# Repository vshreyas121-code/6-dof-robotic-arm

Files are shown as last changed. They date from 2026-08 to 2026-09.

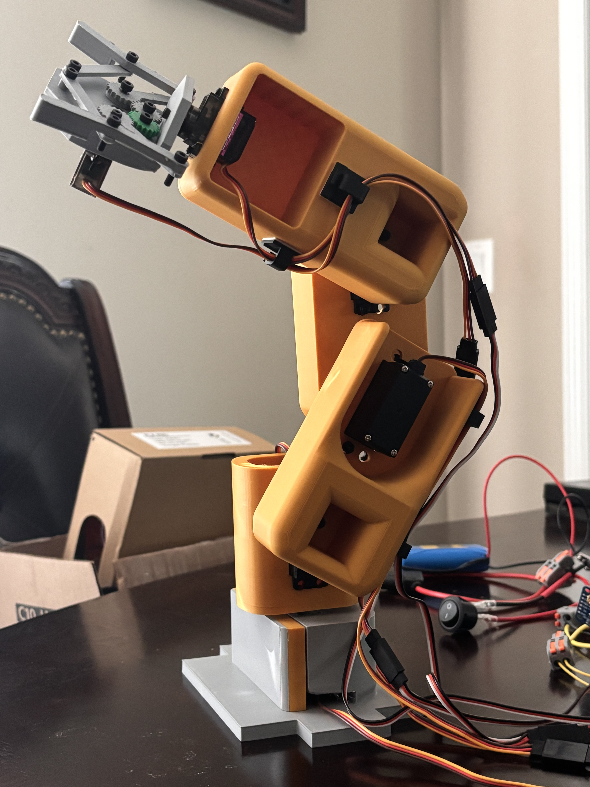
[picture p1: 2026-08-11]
images/finished-arm.jpeg

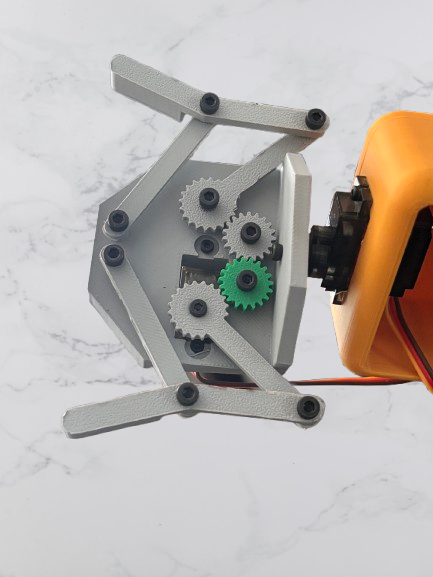
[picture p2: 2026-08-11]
images/gripper.png

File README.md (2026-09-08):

# DIY 6-DOF Robotic Arm

## 📌 Project Overview

This project documents the design, CAD modeling, assembly, wiring, and programming of a custom 6-DOF robotic arm. The robotic arm is controlled using an Arduino Mega 2560, a PCA9685 16-channel servo driver, and six positional servo motors. The mechanical components were designed in Onshape and assembled using 3D-printed parts, servo horns, screws, and hardware.

The arm is powered by a LiPo battery, fuse, switch, and 5V buck converter system. Servo angles are controlled through serial commands sent from a computer through the Arduino Serial Monitor.

The project provided practical experience in robotics, CAD design, embedded systems, servo control, electrical wiring, hardware-software integration, and mechanical troubleshooting.

---

## 🚀 Features

 -  6-DOF robotic arm movement
 - Individual servo motor control
 - Serial angle control through a computer
 - Arduino Mega 2560 control system
 - PCA9685 16-channel PWM servo driver
 - Custom robotic arm components designed in Onshape
 - 3D-printed mechanical assembly
 - External LiPo battery and 5V buck-converter power system
 - Servo angle constraints for safe operation
 - Modular and easy-to-understand Arduino code
 - Planned future autonomous pick-and-place and leader-follower control features

---

## 🛠 Hardware Components

 - Arduino Mega 2560
 - PCA9685 16-Channel Servo Driver
 - 4 MG995 Positional Servo Motors
 - 2 MG90S Positional Servo Motors
 - Custom 3D-Printed Robotic Arm Mechanical Assembly
 - LiPo Battery
 - Fuse and Fuse Holder
 - Power Switch
 - 5V Buck Converter
 - Jumper Wires
 - Servo Extension Wires
 - Screws, Nuts, and Servo Horns

---

## 💻 Software & Tools

 - Onshape
 - VS Code
 - Arduino Framework / Arduino Libraries
 - GitHub

---

## ⚙️ Technologies Used

 - Arduino Mega 2560
 - PCA9685 I2C PWM Servo Control
 - Onshape CAD Design
 - 3D Printing
 - Robotics & Automation
 - Hardware-Software Integration

---

## 📂 Project Structure

```
├── 📁cad/
│   ├── 📁step/
│   │   ├── 6-dof-robotic-arm.step
│   │   └── assembled-gripper.step
│   ├── 📁STL/
│   │   ├── 📁base/
│   │   │   ├── base-wall.stl
│   │   │   └── base.stl
│   │   ├── 📁elbow/
│   │   │   └── elbow.stl
│   │   ├── 📁gripper/
│   │   │   ├── 📁claw/
│   │   │   │   ├── left-claw.stl
│   │   │   │   └── right-claw.stl
│   │   │   ├── 📁gears/
│   │   │   │   ├── 2x-small-gear.stl
│   │   │   │   ├── big-gear-left.stl
│   │   │   │   └── big-gear-right.stl
│   │   │   ├── 2x-linkage.stl
│   │   │   └── palm.stl
│   │   ├── 📁shoulder/
│   │   │   └── shoulder.stl
│   │   ├── 📁waist/
│   │   │   └── waist.stl
│   │   └── 📁wrist/
│   │       └── wrist.stl
│   └── Onshape-Link.md
├── 📁code/
│   ├── 6 DOF Robotic Arm.ino
├── 📁docs/
│   ├── assembly-guide.pdf
│   └── wiring-diagram.png
├── 📁electronics/
│   ├── parts-list.pdf
│   └── wiring-diagram.png
├── 📁images/
│   ├── Robotic_Arm.mov
│   ├── finished-arm-cad.png
│   ├── finished-arm.jpeg
│   └── gripper.png
├── LICENSE
└── README.md

```

---

## 🔄 Working Principle

1. The LiPo battery provides power to the system through a fuse and power switch.
2. The battery voltage is sent to a buck converter, which supplies regulated 5V power to the Arduino Mega 2560, PCA9685 servo driver logic, and PCA9685 servo power rail.
3. The Arduino Mega communicates with the PCA9685 using I2C communication through the SDA and SCL pins.
4. The PCA9685 generates PWM signals for each servo motor.
5. Six positional servos are connected to PCA9685 channels 0 through 5.
6. The user enters six requested servo angles through the computer Serial Monitor.
7. The Arduino reads the serial command, applies safe angle limits, and commands each servo to move to its requested position.
8. The robotic arm performs the requested movement in real time.

---

## 🎯 Skills Demonstrated

 - Robotics
 - Arduino Development
 - Servo Motor Control
 - Serial Communication
 - CAD Design
 - 3D Printing
 - Electrical Wiring and Power Distribution
 - Hardware Integration
---

## 👨‍💻 My Contribution

 - Designed the complete robotic arm in Onshape.

 - Created CAD models for the mechanical arm components and exported files for fabrication.

 - Assembled the robotic arm using custom 3D-printed components, positional servos, servo horns, screws, nuts, and washers.

 - Designed and documented the power-distribution system using a LiPo battery, fuse, switch, and 5V buck converter.

 - Wired the Arduino Mega 2560, PCA9685 servo driver, and six servo motors.

 - Programmed the Arduino using VS Code.

 - Created serial-based servo-angle control for all six arm joints.

 - Tested, calibrated, and optimized servo motor movement and mechanical alignment.

 - Performed complete hardware-software integration and system testing.

---
## 🎥 Video

https://github.com/user-attachments/assets/5076b947-41e4-44dd-bf85-272afc0f2e92

---
## 📚 Author

**Shreyas Venkatachalam**

High School student interested in robotics, mechanical design, and embedded systems.

I designed, modeled, assembled, and programmed this 6-DOF robotic arm using Onshape, 3D-printed components, an Arduino Mega 2560, a PCA9685 servo driver, and six servo motors. This project allowed me to explore robotic motion, CAD design, 3D printing, electrical wiring, serial communication, and iterative troubleshooting.

 - Email: [VShreyas121@gmail.com](mailto:VShreyas121@gmail.com)

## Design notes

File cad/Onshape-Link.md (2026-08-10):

https://cad.onshape.com/documents/33eb4faf4d72cb4e8d812189/w/d14da05585980880eb853401/e/e9817a7469a7e6512d3307ce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

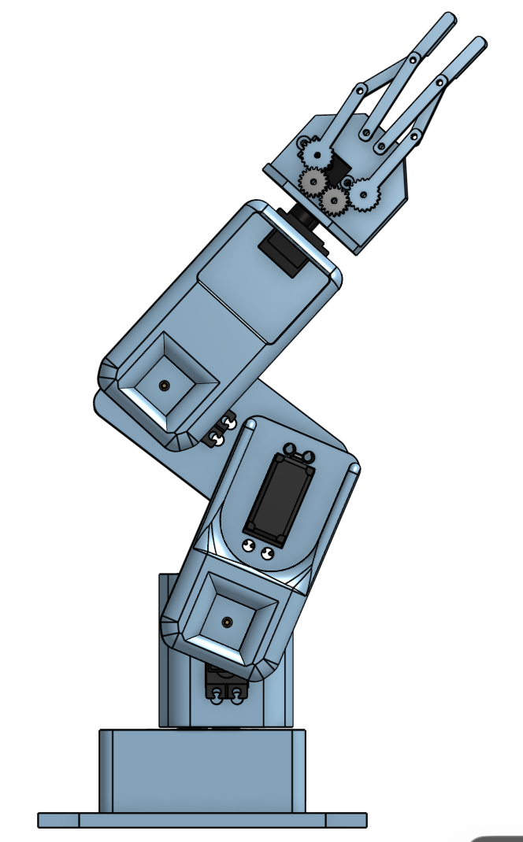
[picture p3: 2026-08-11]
images/finished-arm-cad.png

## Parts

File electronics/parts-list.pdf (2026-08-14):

Parts List

1. 12.6 V LiPo Battery 3000 mAh
2. Fuse (optional)
3. Switch
4. 12.6 V to 5 V DC Buck Converter
5. Arduino Mega 2560
6. PCA9685 Servo Controller
7. 1 to 2 Lever Wire Connecters (optional)
8. M2, M2.5, M3 screws
9. Jumper Wires

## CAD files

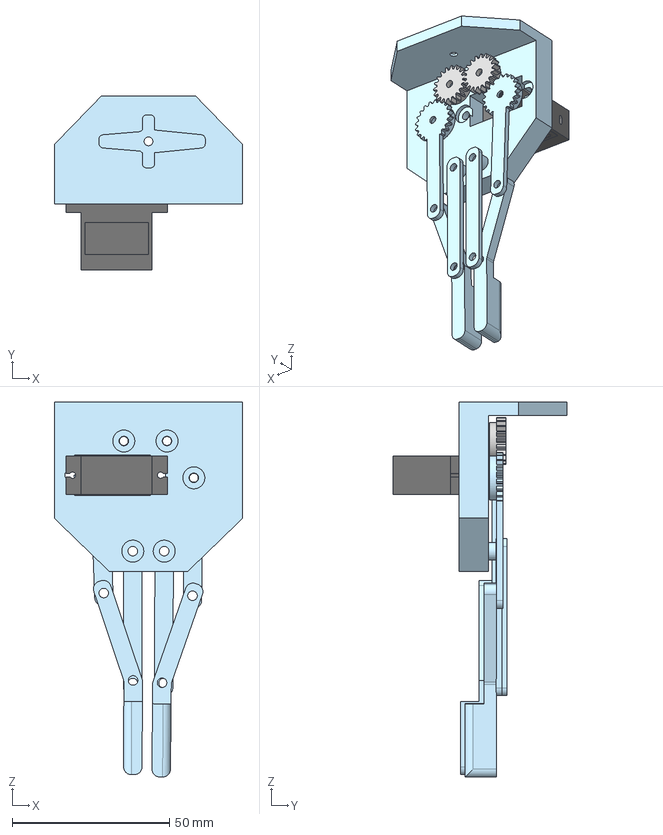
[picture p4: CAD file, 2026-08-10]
cad/step/assembled-gripper.step
60.0 x 55.5 x 119.4 mm
Cylindre001
axe
Tube002
Cylindre
Small gear x 2
Cylindre002
Tube001
base001
Tube
etiquette001
Big gear Right
Big gear Left
etiquette

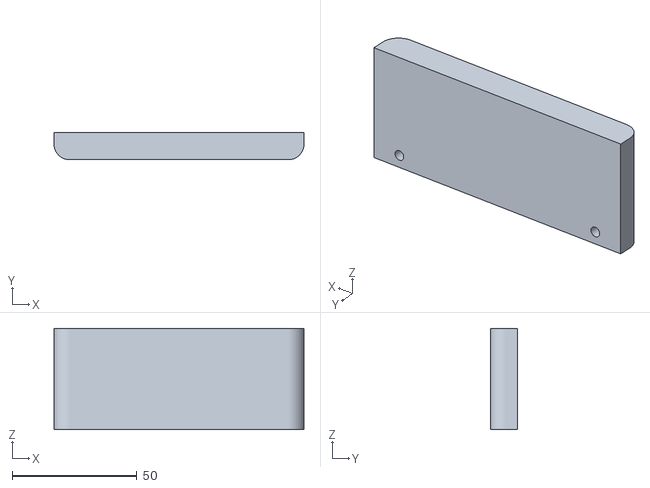
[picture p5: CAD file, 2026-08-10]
cad/STL/base/base-wall.stl
100.0 x 11.0 x 40.5

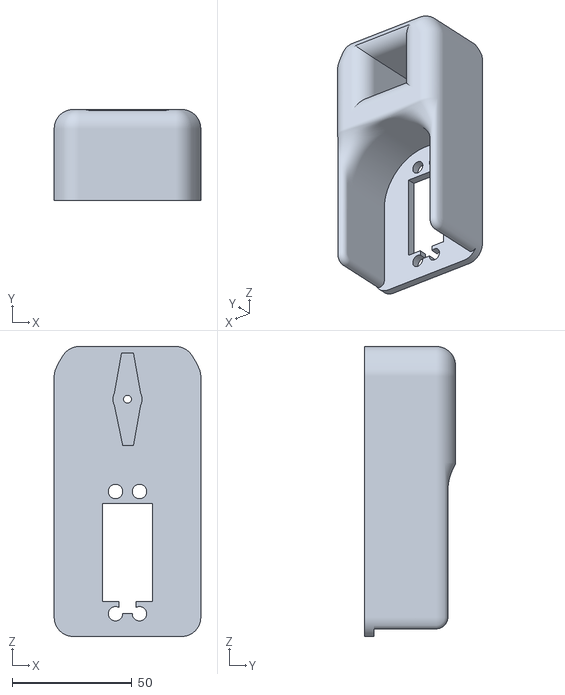
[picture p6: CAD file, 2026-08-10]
cad/STL/elbow/elbow.stl
61.2 x 38.0 x 121.0

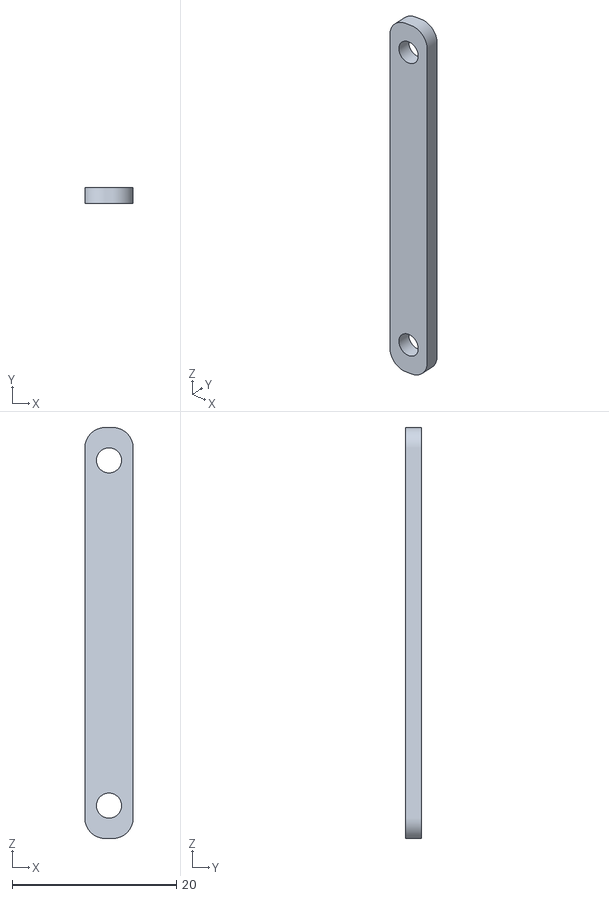
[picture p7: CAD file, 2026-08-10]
cad/STL/gripper/2x-linkage.stl
5.89 x 2.00 x 50.0

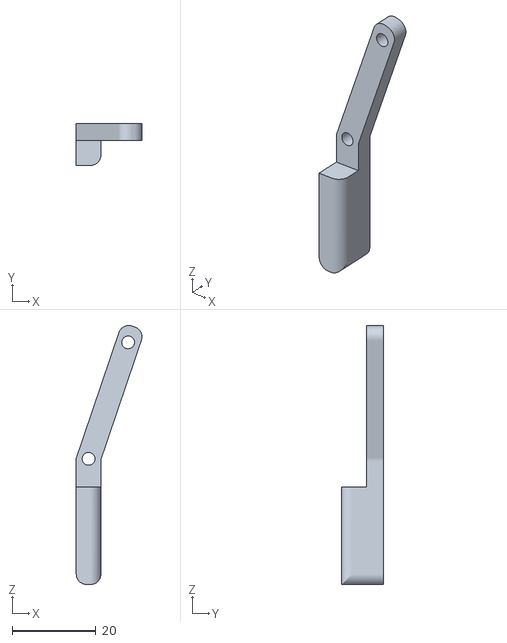
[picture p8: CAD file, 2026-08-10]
cad/STL/gripper/claw/right-claw.stl
15.7 x 10.0 x 61.8

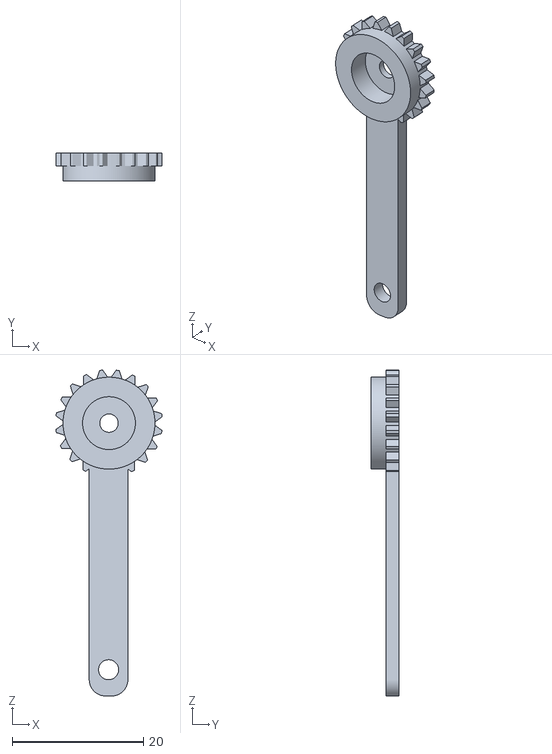
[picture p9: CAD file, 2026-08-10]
cad/STL/gripper/gears/big-gear-right.stl
16.2 x 4.30 x 49.6

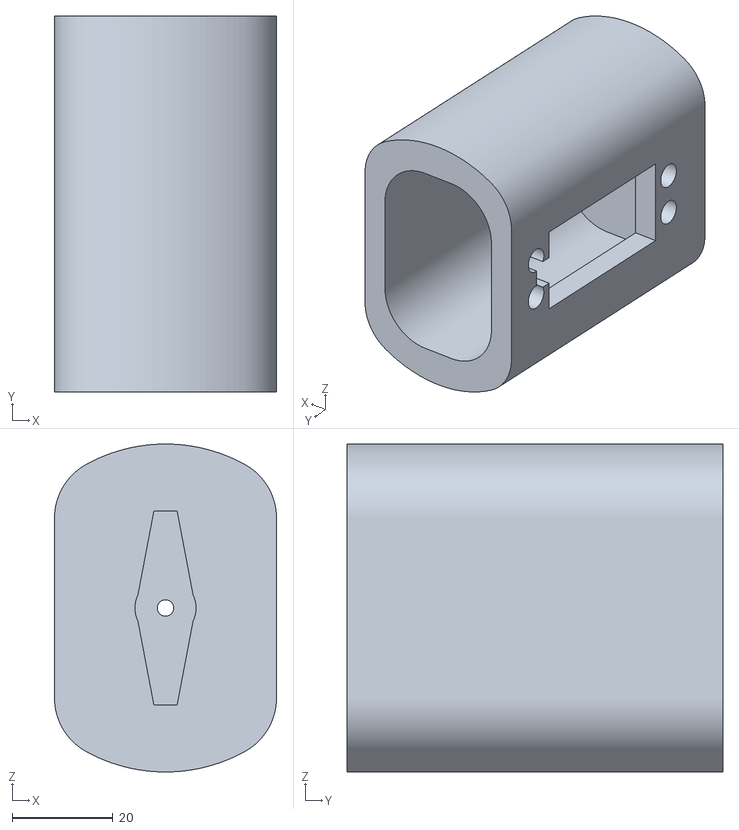
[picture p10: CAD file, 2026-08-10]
cad/STL/waist/waist.stl
44.0 x 74.5 x 65.0

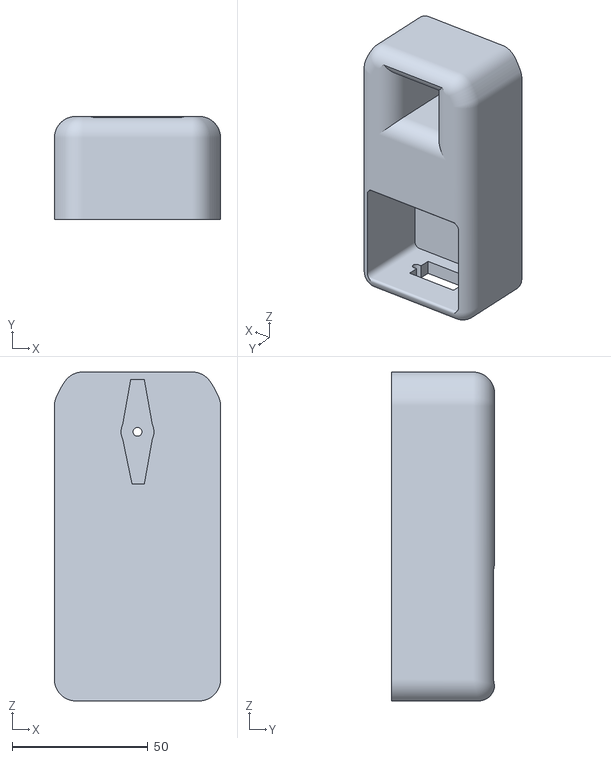
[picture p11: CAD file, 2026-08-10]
cad/STL/wrist/wrist.stl
61.2 x 38.0 x 121.0

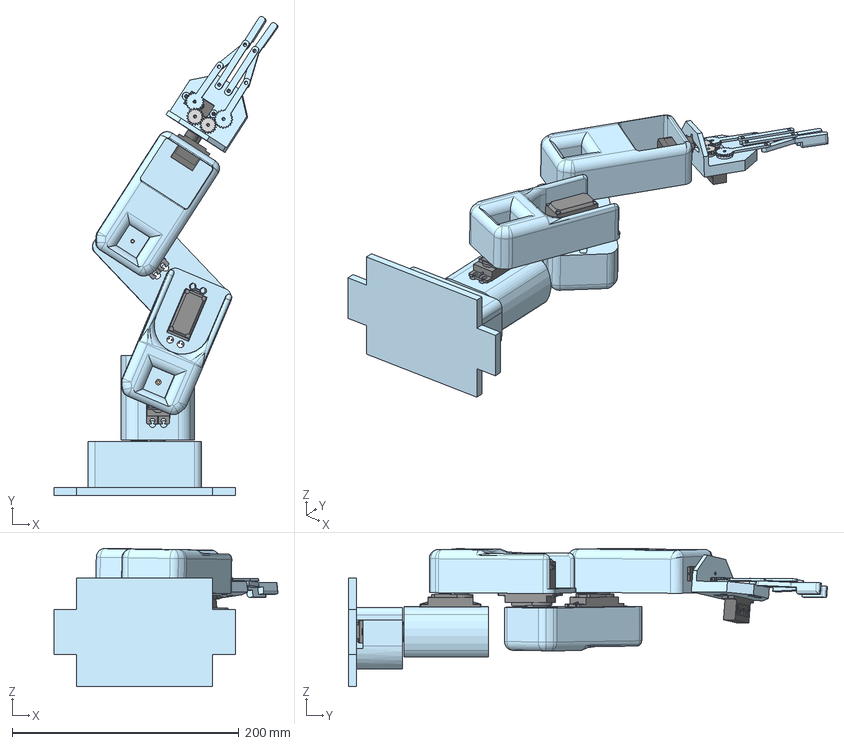
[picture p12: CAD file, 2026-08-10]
cad/step/6-dof-robotic-arm.step
197.6 x 422.5 x 122.1 mm
axe x 2
Cylindre001 x 2
Cylindre002 x 2
Cylindre x 2
Tube002 x 2
base001 x 2
Tube001 x 2
etiquette x 2
etiquette001 x 2
Tube x 2
Small gear x 2
Big gear Right
Big gear Left

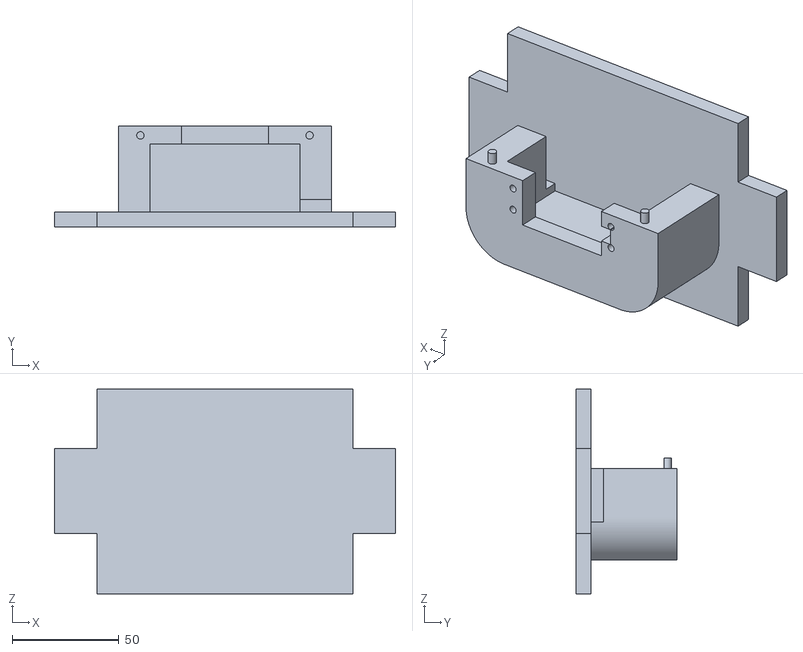
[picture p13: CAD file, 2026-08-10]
cad/STL/base/base.stl
160.0 x 47.5 x 96.0

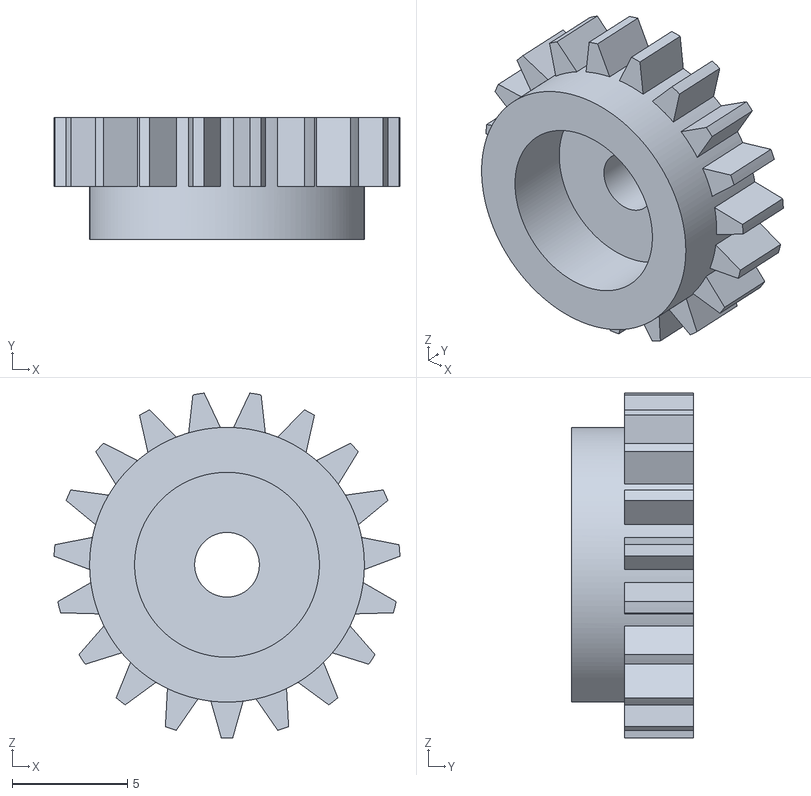
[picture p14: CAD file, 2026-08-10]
cad/STL/gripper/gears/2x-small-gear.stl
15.0 x 5.30 x 14.9

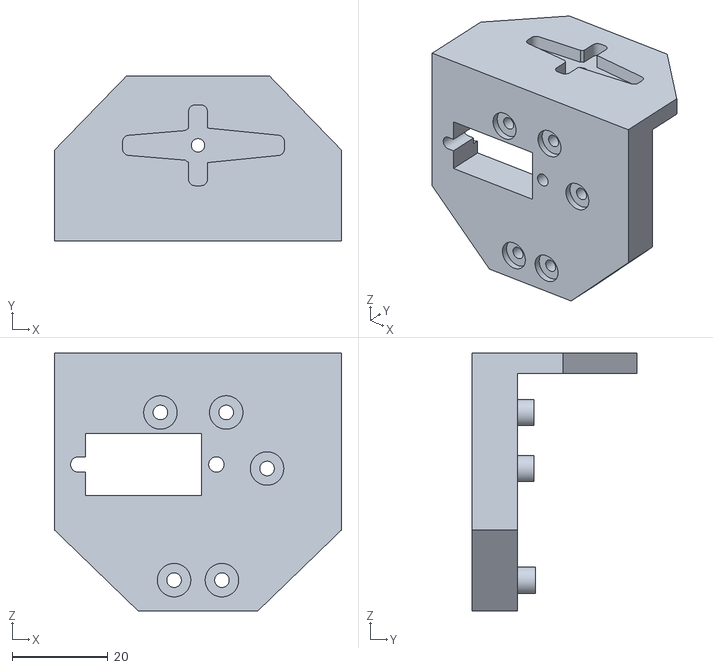
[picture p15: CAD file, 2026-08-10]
cad/STL/gripper/palm.stl
60.0 x 34.5 x 53.9

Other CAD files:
cad/STL/gripper/claw/left-claw.stl
cad/STL/gripper/gears/big-gear-left.stl

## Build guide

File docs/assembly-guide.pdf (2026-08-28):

# Assembly Guide

This guide explains how I assembled the mechanical structure of my custom 6-DOF robotic arm. The parts were designed in Onshape, 3D printed, and assembled with hobby servos, screws

Hardware
- All parts were described in further detail in the Parts List in the GitHub repository

Before Assembly
1. Remove support material from the printed parts.
2. Clean the screw holes and servo openings.
3. Use a small file or sandpaper if a part does not fit.
4. Check each part against the Onshape model.
5. Test-fit the parts without screws first.
6. Make sure moving joints can rotate without rubbing.

Assembly
1. Finish prep steps above for all parts
2. Mount each servo in its matching printed location as seen on the CAD
3. Assemble the arm from the base upward, attaching the arm sections, wrist components, and gripper
4. Install servo horns and linkage components of the gripper leaving enough slack for the joints to move
5. Route the servo wires along the arm, leaving enough slack for each joint to move freely
6. Check for interference, pinched wires, or loose screws before moving on to code

Leaving the screws slightly loose during the first assembly makes it easier to align the parts. Fully tighten the hardware after checking that each joint moves correctly.

Servo Horn Alignment

Servo horns should be installed after the servos have been moved to their neutral position in the control code.

The general process is:

1. Temporarily install the servo without permanently attaching the horn.
2. Use the test code to move the servo to its center position.
3. Turn off power.
4. Place the horn in the closest mechanically centered position.
5. Install the horn screw.
6. Attach the linkage or printed joint.
7. Test the movement using a small range.

The neutral position for this project is approximately 90 degrees, but the physical “straight” position may be different for each joint because the servos are mounted in different orientations.

Wire Routing

Route the servo wires so they:

- Do not pass through screw holes.
- Do not get pinched by moving parts.
- Do not rub against sharp printed edges.
- Have enough slack for the joint to move.
- Stay away from servo horns and gears.
- Can be removed later for repairs.

Use small cable ties, adhesive clips, or printed cable guides where appropriate. Do not make the wires so tight that they pull on the servo connectors when the arm moves.

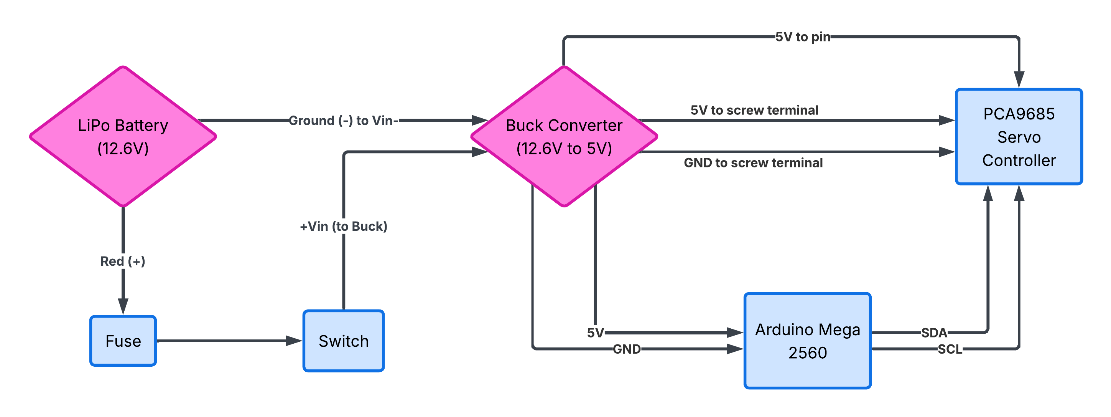
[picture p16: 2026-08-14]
docs/wiring-diagram.png

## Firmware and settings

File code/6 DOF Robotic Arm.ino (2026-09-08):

/*
  6-DOF Arduino Robot Arm with PCA9685 Servo Driver
  - Arduino Mega 2560
  - PCA9685 16-channel servo driver
  - 6 positional servos connected to PCA9685 channels 0..5

  Wiring assumed:
  - Arduino 5V -> PCA9685 VCC
  - Arduino GND -> PCA9685 GND
  - Arduino SDA -> PCA9685 SDA
  - Arduino SCL -> PCA9685 SCL
  - PCA9685 V+ / screw terminal -> 5V servo power rail
  - PCA9685 GND -> common ground with servos

  Angle convention:
  - 90 degrees = middle / neutral position for every joint
  - Angles are accepted from 0 to 180

  Serial Monitor usage:
  - Open Serial Monitor at 115200 baud
  - Type six integers on one line in this order:
    base shoulder elbow wristPitch wristRoll gripper
  - Example:
    90 45 120 90 90 30
*/

#include <Wire.h>
#include <Adafruit_PWMServoDriver.h>

// Create the PCA9685 object.
Adafruit_PWMServoDriver pwm = Adafruit_PWMServoDriver(0x40);

// PCA9685 channel mapping.
const uint8_t CHANNEL_BASE = 0;
const uint8_t CHANNEL_SHOULDER = 1;
const uint8_t CHANNEL_ELBOW = 2;
const uint8_t CHANNEL_WRIST_PITCH = 3;
const uint8_t CHANNEL_WRIST_ROLL = 4;
const uint8_t CHANNEL_GRIPPER = 5;

// Servo pulse width range for 0..180 degrees.
const uint16_t SERVOMIN = 150;
const uint16_t SERVOMAX = 600;

// 50 Hz is the standard update rate for servos.
const uint16_t PWM_FREQUENCY = 50;

const uint8_t POSITION_COUNT = 10;
const uint16_t MOTION_STEP_DELAY_MS = 35;
const uint16_t POSITION_DELAY_MS = 500;

const uint8_t positions[POSITION_COUNT][6] = {
    {90, 90, 90, 100, 0, 130},
    {90, 120, 90, 100, 0, 130},
    {90, 135, 90, 100, 0, 130},
    {90, 135, 90, 100, 0, 90},
    {90, 110, 90, 100, 0, 90},
    {90, 90, 90, 100, 0, 90},
    {130, 90, 90, 100, 0, 90},
    {130, 120, 90, 100, 0, 90},
    {130, 135, 90, 100, 0, 90},
    {130, 135, 90, 100, 0, 130}};

uint8_t currentAngles[6] = {90, 90, 90, 90, 90, 90};
bool sequenceHasRun = false;

// Command one servo to a target angle from 0 to 180 degrees.
void setServoAngle(uint8_t channel, uint8_t angle)
{
  angle = constrain(angle, 0, 180);

  uint16_t pulse = map(angle, 0, 180, SERVOMIN, SERVOMAX);
  pwm.setPWM(channel, 0, pulse);
}

void writeAllAngles(const uint8_t angles[6])
{
  for (uint8_t joint = 0; joint < 6; joint++)
  {
    setServoAngle(joint, angles[joint]);
  }
}

void moveToPosition(const uint8_t targetAngles[6])
{
  uint8_t steps = 0;

  for (uint8_t joint = 0; joint < 6; joint++)
  {
    uint8_t distance = abs((int)targetAngles[joint] - currentAngles[joint]);
    if (distance > steps)
    {
      steps = distance;
    }
  }

  for (uint8_t step = 1; step <= steps; step++)
  {
    uint8_t intermediateAngles[6];

    for (uint8_t joint = 0; joint < 6; joint++)
    {
      int difference = (int)targetAngles[joint] - currentAngles[joint];
      intermediateAngles[joint] = currentAngles[joint] + (difference * step) / steps;
    }

    writeAllAngles(intermediateAngles);
    delay(MOTION_STEP_DELAY_MS);
  }

  for (uint8_t joint = 0; joint < 6; joint++)
  {
    currentAngles[joint] = targetAngles[joint];
  }
}

// Parse a line of six integers from Serial.
bool parseSixAngles(String input, int angles[6])
{
  input.trim();

  if (input.length() == 0)
  {
    return false;
  }

  char buffer[64];
  input.toCharArray(buffer, sizeof(buffer));

  char *token = strtok(buffer, " \t\r\n");
  int count = 0;

  while (token != NULL)
  {
    if (count >= 6)
    {
      return false;
    }

    char *endPtr;
    long value = strtol(token, &endPtr, 10);

    if (endPtr == token || *endPtr != '\0')
    {
      return false;
    }

    angles[count++] = constrain((int)value, 0, 180);
    token = strtok(NULL, " \t\r\n");
  }

  return count == 6;
}

void setup()
{
  Serial.begin(115200);
  Wire.begin();

  pwm.begin();
  pwm.setOscillatorFrequency(27000000);
  pwm.setPWMFreq(PWM_FREQUENCY);

  // Move all servos to the safe middle position.
  writeAllAngles(currentAngles);

  Serial.println("Robot arm ready.");
  Serial.println("Send 6 angles in this order:");
  Serial.println("base shoulder elbow wristPitch wristRoll gripper");
  Serial.println("Example: 90 45 120 90 90 30");
  Serial.println("Running the 10-position motion sequence.");
}

void loop()
{
  if (!sequenceHasRun)
  {
    for (uint8_t positionIndex = 0; positionIndex < POSITION_COUNT; positionIndex++)
    {
      moveToPosition(positions[positionIndex]);
      delay(POSITION_DELAY_MS);
    }

    sequenceHasRun = true;
  }

  if (Serial.available() > 0)
  {
    String inputLine = Serial.readStringUntil('\n');
    inputLine.trim();

    int angles[6];
    if (parseSixAngles(inputLine, angles))
    {
      uint8_t targetAngles[6];
      for (uint8_t joint = 0; joint < 6; joint++)
      {
        targetAngles[joint] = angles[joint];
      }
      moveToPosition(targetAngles);

      Serial.print("Moved servos to: ");
      Serial.print(angles[0]);
      Serial.print(" ");
      Serial.print(angles[1]);
      Serial.print(" ");
      Serial.print(angles[2]);
      Serial.print(" ");
      Serial.print(angles[3]);
      Serial.print(" ");
      Serial.print(angles[4]);
      Serial.print(" ");
      Serial.println(angles[5]);
    }
    else
    {
      Serial.println("Invalid input. Please send exactly 6 integers.");
      Serial.println("Example: 90 45 120 90 90 30");
    }
  }
}

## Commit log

2026-08-10 Create 2x-small-gear
2026-08-10 Create right-claw
2026-08-10 Add 2x-small-gear STL file
    [2x-small-gear.stl]
2026-08-14 Create Wiring Diagram.png
2026-09-08 Rename 6 to 6 DOF Robotic Arm.ino
2026-09-08 Add smooth one-shot arm motion sequence
2026-09-08 Add code directory with Arduino file
